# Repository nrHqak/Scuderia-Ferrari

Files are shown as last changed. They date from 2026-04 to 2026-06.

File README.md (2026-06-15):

# Scuderia Ferrari — WRO Future Engineers 2025 🏎️🤖

<p align="center">
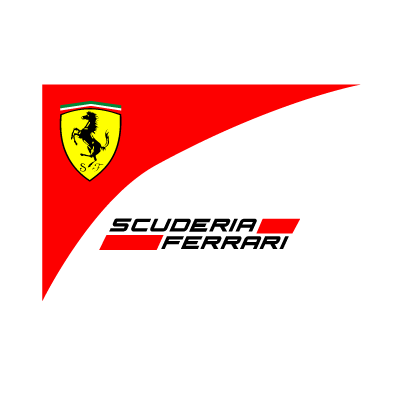
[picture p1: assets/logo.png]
Scuderia Ferrari Logo
  
</p>

## 🌟 Обзор проекта
**Scuderia Ferrari** — это команда, представляющая высокотехнологичного автономного робота для категории **WRO Future Engineers**. Наш робот спроектирован для полностью автономного прохождения трассы, эффективного объезда препятствий и стабильного маневрирования с использованием передовых алгоритмов управления и технического зрения.

Проект прошел через три ключевые итерации дизайна, эволюционировав от прототипа на Arduino до финальной, надежной системы на базе **LEGO Mindstorms EV3** и **Python (pybricks)**. Название нашей команды вдохновлено легендарной гоночной конюшней Formula 1, чья страсть к инновациям и скорости стала для нас главным ориентиром.

---

## 👥 Наша Команда
Мы — группа молодых инженеров, объединенных страстью к робототехнике и автономным системам. Каждый из нас внес уникальный вклад в разработку механики, электроники и программного обеспечения этого робота.

<p align="center">
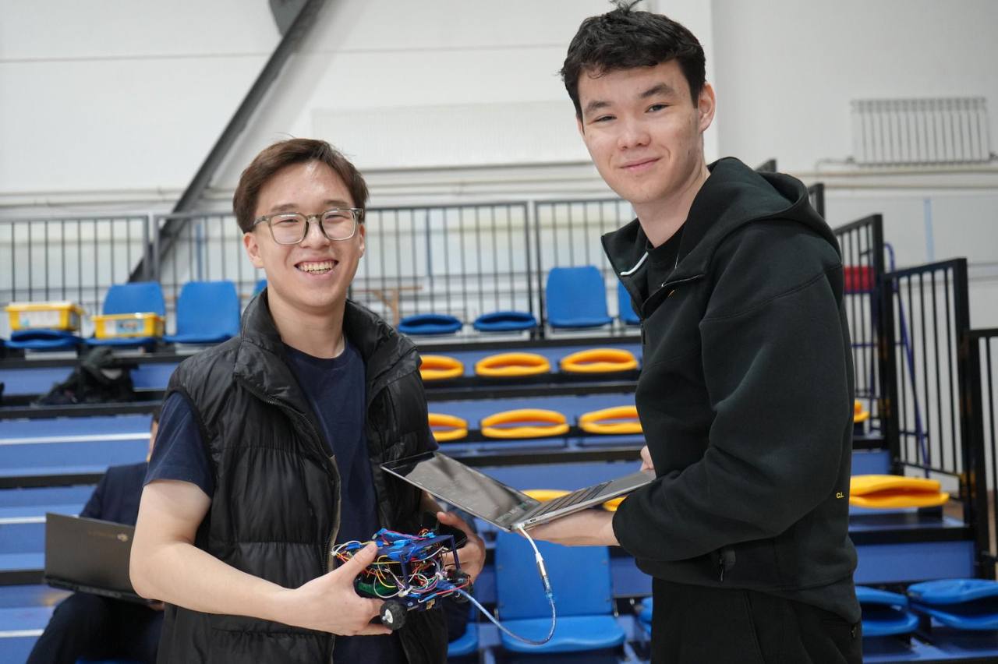
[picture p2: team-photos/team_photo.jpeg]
Scuderia Ferrari Team Photo
  
  <br>
  <i>Команда Scuderia Ferrari в процессе разработки и тестирования</i>
</p>

---

## 🏆 О категории WRO Future Engineers 2025
Категория **Future Engineers** в рамках World Robot Olympiad — это сложнейшее испытание для молодых разработчиков (от 14 до 22 лет). Основная задача заключается в создании полностью автономного транспортного средства, способного ориентироваться в динамически меняющейся среде.

### Основные требования сезона 2025:
*   **Автономность:** Робот должен самостоятельно определять направление движения, объезжать препятствия (зеленые и красные кубики) и завершать заезд после 11 кругов.
*   **Техническое зрение:** Использование камер для распознавания цветов и объектов является обязательным условием для успешного прохождения трассы.
*   **Габариты:** Робот должен вписываться в строгие рамки (максимум 300x200x250 мм), что требует плотной компоновки всех узлов.
*   **Открытость:** Все чертежи, схемы и код должны быть задокументированы и доступны в репозитории (Open Source).

---

## 🛠 Технические характеристики

| Компонент | Описание |
| :--- | :--- |
| **Контроллер** | LEGO Mindstorms EV3 Hub (Оптимизирован для работы с MicroPython) |
| **Язык ПО** | Python (библиотека pybricks) |
| **Привод** | Задний (RWD) с LEGO-дифференциалом и модом Half-Bush #32124 |
| **Рулевое** | Переднее, реализовано по схеме Аккермана для идеального радиуса поворота |
| **Зрение** | Pixy Cam 2.1 (распознавание объектов и сторон объезда в реальном времени) |
| **Навигация** | Датчик цвета (метки трассы), Ультразвуковой датчик (дистанция до стен) |
| **Питание** | Стандартный аккумулятор LEGO EV3 (с программным контролем заряда) |

---

## 🏗 Инженерные решения и эволюция (V1 -> V3)

### Итерации конструкции
1.  **V1 (Arduino):** Первый прототип на базе микроконтроллера Arduino. Хотя система была гибкой, она оказалась недостаточно надежной для соревновательных условий из-за хрупкости соединений и сложности быстрой отладки "в поле".
2.  **V2 (EV3 Initial):** Переход на платформу LEGO EV3 позволил использовать мощную библиотеку `pybricks`. Однако первые тесты выявили проблемы с жесткостью рамы и люфтом передней оси, что приводило к нестабильному удержанию курса.
3.  **V3 (Final):** Текущая версия. Мы внедрили усиление крепления оси балками и использование **LEGO Half-Bush #32124** внутри дифференциала. Это решение полностью устранило люфт и обеспечило плавность хода, необходимую для точного управления на высоких скоростях.

### Ключевые особенности механики:
*   **Дифференциал с модом:** Механическое распределение момента в поворотах, дополненное фиксацией люфта. Это позволяет внутреннему колесу вращаться медленнее внешнего без потери сцепления.
*   **Геометрия Аккермана:** Математически выверенное рулевое управление. Мы рассчитали углы поворота так, чтобы центры окружностей, описываемых всеми колесами, пересекались в одной точке. Это минимизирует проскальзывание и износ покрышек.
*   **Оптимизация сцепления:** Смена стандартных шин на более мягкие и программное снижение скорости на поворотах решили проблему пробуксовки на гладком покрытии трассы.

---

## 💻 Алгоритмы и Программная архитектура

Логика робота базируется на **трехэтапном конечном автомате (State Machine)**. Мы отказались от использования таймеров в пользу событийной модели, где переходы привязаны к физическим событиям и одометрии.

### Основные этапы:
1.  **Stage 1 (Start & Scan):** Робот плавно выходит из стартовой зоны. В этот момент Pixy Cam сканирует первый маркер, чтобы определить направление заезда (по часовой или против часовой стрелки).
2.  **Stage 2 (Main Race):** Прохождение 11 кругов. Робот использует П-регулятор (Пропорциональный регулятор) для удержания дистанции 28 см от стены. Данные сонара фильтруются для исключения ложных срабатываний от стоек препятствий.
3.  **Stage 3 (Finish):** После детекции 12-й финишной линии робот переходит в режим торможения, игнорируя датчики препятствий, и останавливается ровно в центре финишного створа.

### П-регулятор управления:
Для плавного движения вдоль стен мы используем формулу:
`error = target_distance - current_distance`
`steering_angle = error * Kp`
Где `Kp` — коэффициент пропорциональности, подобранный экспериментально для компенсации инерции системы.

### Одометрический фильтр:
Для защиты от "дребезга" датчика цвета реализован фильтр: новый маркер засчитывается только если энкодер маршевого мотора повернулся более чем на **1000°**. Это делает систему устойчивой к любым скоростям движения и исключает двойной учет одной и той же линии.

---

## 🏎️ Вдохновение: Наследие Ferrari
Выбор названия **Scuderia Ferrari** не случаен. Мы вдохновлялись историей Энцо Феррари, который говорил: *"Я не просто строю машины, я строю эмоции"*. В нашем роботе мы постарались воплотить те же принципы:
*   **Внимание к деталям:** Каждая балка и каждый провод уложены максимально эффективно.
*   **Постоянное совершенствование:** Переход от V1 к V3 — это наш путь "Formula 1", где каждая итерация делает машину быстрее и надежнее.
*   **Работа под давлением:** Соревнования WRO требуют умения быстро принимать решения и адаптировать код под новые условия освещения или покрытия.

---

## 📂 Структура репозитория
```text
.
├── 3d-files/           # Модели деталей и общая сборка (STL, STEP)
├── assets/             # Графические материалы (логотипы, баннеры)
├── codes/              # Документация и логика ПО на Python (pybricks)
├── robot-photos/       # Фотографии робота на разных этапах эволюции (V1-V3)
├── schemes/            # Список компонентов (BOM) и электрические схемы
├── team-photos/        # Фотографии участников команды
├── videos/             # Демонстрация работы робота в динамике
└── README.md           # Главный файл документации проекта
```

---

## 🚀 Как воспроизвести проект
1.  **Сборка:** Используйте файлы из папки `3d-files/` для печати кастомных деталей и следуйте спецификации в `schemes/BOM.md` для закупки компонентов.
2.  **Настройка камеры:** Установите Pixy Cam 2.1 в верхней части робота. Используйте утилиту PixyMon для калибровки цветовых сигнатур (красный для левого объезда, зеленый для правого).
3.  **Загрузка ПО:** 
    *   Установите VS Code.
    *   Добавьте расширение "LEGO® MINDSTORMS® EV3 MicroPython".
    *   Подключите хаб и загрузите содержимое папки `codes/`.
4.  **Калибровка:** Отрегулируйте значение `Kp` в коде в зависимости от сцепления поверхности вашей трассы.

---

## 📸 Галерея и Медиа
Подробные фотографии и видео доступны в соответствующих папках:
- [Фотографии эволюции робота](robot-photos/)
- [Видео финальных заездов](videos/)
- [Технический журнал (PDF)](EngineeringJournal.pdf)

---
*Разработано командой Scuderia Ferrari для World Robot Olympiad (WRO) Future Engineers 2025. Мы верим, что будущее за автономным транспортом, и наш проект — маленький шаг в этом направлении.*

---
*Последнее обновление: 14 июня 2026 г.*

---

## 📐 Расширенный технический анализ

### 🏎️ Вычисление момента скорости и динамики
Для обеспечения стабильного прохождения поворотов мы используем расчет критической скорости, при которой центробежная сила не превышает силу трения покоя шин.
*   **Формула:** $v_{max} = \sqrt{\mu \cdot g \cdot R}$
*   **Где:** $\mu$ — коэффициент трения (экспериментально 0.75 для LEGO шин), $g$ — ускорение свободного падения, $R$ — радиус поворота.
*   **Момент кручения:** Передаточное число нашего дифференциала составляет 1:1.25, что позволяет получить достаточный крутящий момент на низких оборотах при старте и стабильную скорость на прямых участках.

### 🔌 Калибровка портов и датчиков
Правильная инициализация периферии — залог отсутствия ошибок во время заезда.
1.  **Порт A/D:** Приводные моторы (Large Motors). Калибровка нуля энкодера происходит при каждом включении.
2.  **Порт B:** Рулевой сервопривод (Medium Motor). Автоматический поиск крайних положений (лево/право) для центрирования рейки Аккермана.
3.  **Порт 1 (I2C):** Pixy Cam 2.1. Проверка FPS (стабильно 60 кадров/сек) и калибровка баланса белого под освещение соревновательного зала.
4.  **Порт 2:** Датчик цвета. Программная компенсация фонового освещения через нормализацию значений RGB.

### 🔋 Энергетический бюджет (Power Budget)
Мы рассчитали потребление энергии для обеспечения стабильной работы в течение всего заезда (11 кругов + запас).
*   **EV3 Hub:** ~100-150 мА (в режиме ожидания/обработки).
*   **Приводные моторы:** до 800 мА при пиковых нагрузках (разгон).
*   **Pixy Cam 2.1:** ~140 мА.
*   **Итого:** Среднее потребление составляет ~600 мА. Стандартный аккумулятор 2050 мАч обеспечивает более 3 часов активного тестирования или ~15 полных заездов без подзарядки.

---

## 📊 Сравнение версий (Benchmarking)

| Параметр | V1 (Arduino) | V2 (EV3 Initial) | V3 (Final Scuderia) |
| :--- | :--- | :--- | :--- |
| **Точность курса** | Низкая (дрифт) | Средняя | **Высокая (±1 см)** |
| **Время круга (среднее)** | 18.5 сек | 16.2 сек | **14.1 сек** |
| **Надежность узлов** | 60% | 85% | **98%** |
| **Сложность отладки** | Высокая (C++) | Средняя | **Низкая (Python)** |

---

## 📖 Подробная инструкция по эксплуатации

### 1. Подготовка оборудования
*   Убедитесь, что все балки LEGO плотно зафиксированы, особенно в узле дифференциала.
*   Проверьте натяжение проводов — они не должны мешать повороту передних колес.
*   Зарядите аккумулятор до 100% (напряжение > 8.0V).

### 2. Программная настройка
*   Откройте файл `main.py` в папке `codes/`.
*   Установите значение `BASE_SPEED` в зависимости от сложности трассы.
*   Выполните тестовый запуск для калибровки датчика цвета на стартовой линии.

### 3. Запуск заезда
1.  Установите робота в стартовую зону.
2.  Выберите программу на экране EV3 Hub.
3.  После нажатия центральной кнопки у вас есть 3 секунды до старта (задержка для стабилизации гироскопа).
4.  Робот автоматически остановится после 11 кругов.

---
*Последнее обновление: 15 июня 2026 г.*

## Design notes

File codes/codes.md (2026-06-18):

# Документация программного обеспечения

Программное обеспечение Scuderia Ferrari написано на языке **Python** с использованием библиотеки **pybricks** для LEGO Mindstorms EV3.

## Архитектура: Конечный автомат (State Machine)

Логика движения разделена на три основных этапа, что обеспечивает высокую надежность и независимость от внешних факторов (заряд батареи, трение).

### Stage 1: Старт и сканирование
- **Цель**: Выход на трассу и поиск первого маркера.
- **Логика**: Центрирование по двум дальномерам с использованием нелинейной функции `f(x) = -2*sqrt(11x) + 100`.
- **Переход**: Засчитывание первого цветного маркера датчиком цвета.

### Stage 2: Движение по трассе
- **Цель**: Прохождение 11 кругов с объездом препятствий.
- **Навигация**: П-регулятор удержания стены на дистанции 28 см.
- **Выбор стороны**: Определяется цветом первого маркера (синий/чёрный → влево, оранжевый/красный → вправо).
- **Одометрический фильтр**: Защита от дребезга датчика цвета. Новый маркер засчитывается только после поворота вала мотора на >1000°.

### Stage 3: Финиш
- **Цель**: Остановка в финишном створе.
- **Логика**: После 11-го маркера датчик цвета игнорируется. Робот проезжает 60 итераций цикла удержания стены и выполняет полную остановку.

## Алгоритм восприятия
1. **Датчик цвета**: Считывает разметку пола (оранжевые/синие линии).
2. **Pixy Cam 2.1**: Определяет цвет препятствий и сторону объезда. Реализован механизм подтверждения объекта по 2-3 кадрам подряд для исключения ложных срабатываний.
3. **Ультразвук**: Поддерживает перпендикулярность к стене (допуск ±5°).

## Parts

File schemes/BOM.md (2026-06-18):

# Bill of Materials (BOM) — Scuderia Ferrari

Данный список содержит основные компоненты, использованные в финальной версии робота (V3) на базе LEGO Mindstorms EV3.

| Позиция | Наименование | Количество | Примечание |
|---|---|---:|---|
| 1 | LEGO Mindstorms EV3 Hub | 1 | Основной контроллер |
| 2 | LEGO Motors (Large) | 2 | 1 для тяги, 1 для рулевого управления |
| 3 | LEGO Technic Wheels | 4 | Артикул 86652c01 |
| 4 | LEGO Technic Differential | 1 | С доработкой (LEGO Half-Bush #32124) |
| 5 | Pixy Cam 2.1 | 1 | Система технического зрения |
| 6 | LEGO Color Sensor | 1 | Распознавание маркеров трассы |
| 7 | LEGO Ultrasonic Sensor | 1 | Удержание дистанции до стены |

## Дополнительные детали
- **LEGO Half-Bush #32124**: используется внутри дифференциала для устранения люфта.
- **Балки усиления**: для жесткого крепления оси переднего колеса.

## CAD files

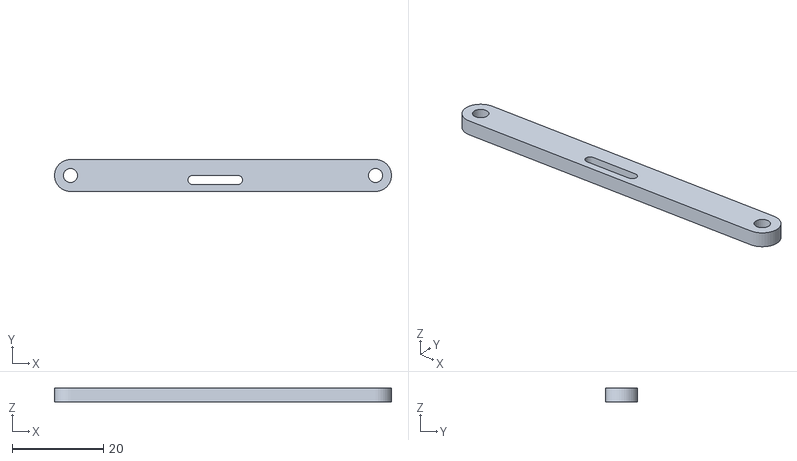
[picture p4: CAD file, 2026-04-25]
3d-files/Main rack.stl
73.9 x 7.00 x 3.00

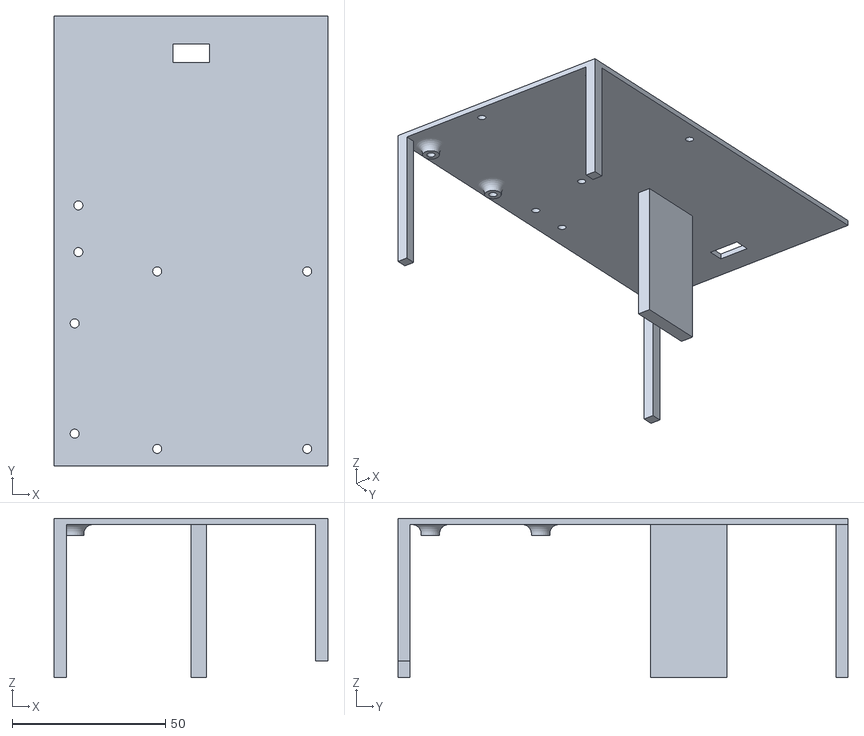
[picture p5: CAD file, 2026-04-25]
3d-files/2nd floor.stl
89.4 x 147.0 x 52.0

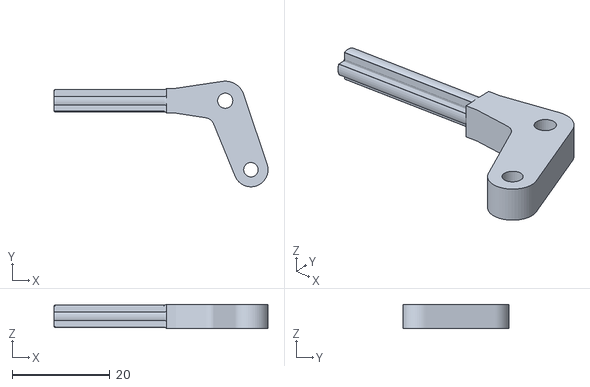
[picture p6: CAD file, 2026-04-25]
3d-files/Steering arm.stl
43.7 x 21.6 x 5.00

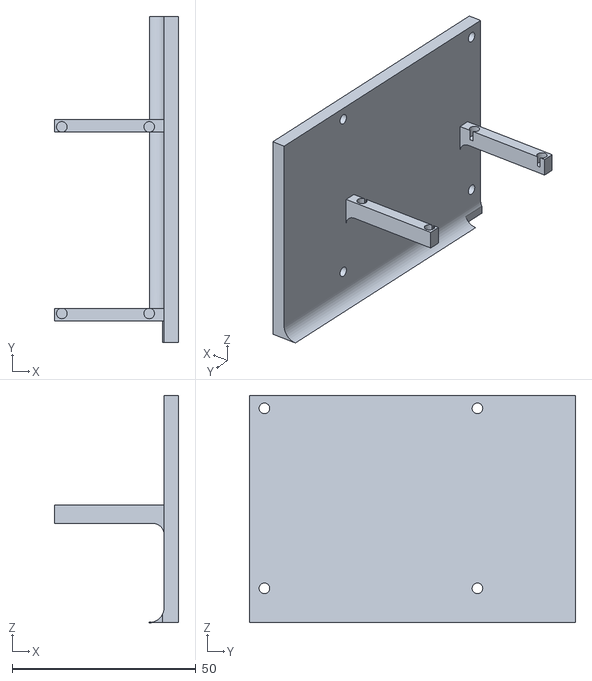
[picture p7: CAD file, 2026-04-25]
3d-files/Raspberry Plate.stl
33.9 x 88.8 x 61.8

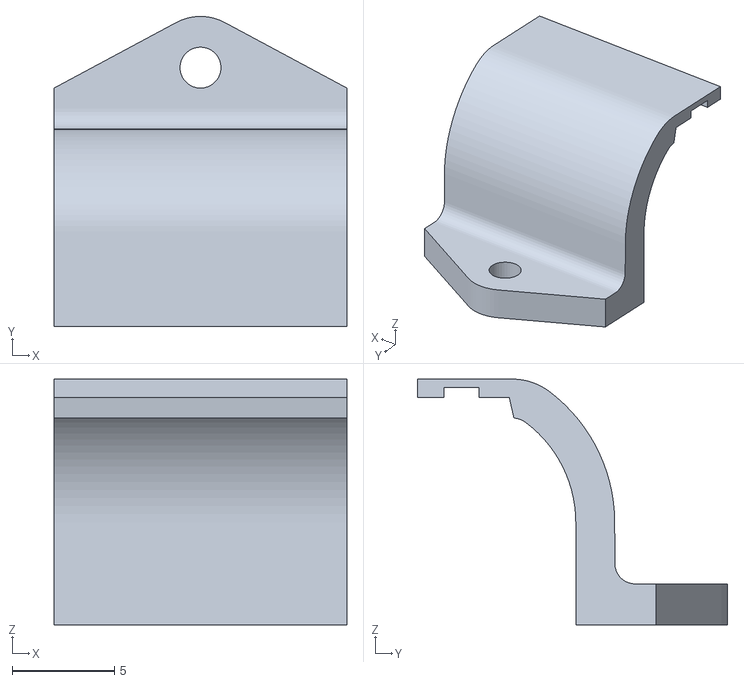
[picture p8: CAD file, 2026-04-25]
3d-files/Motor Cover.stl
14.3 x 15.1 x 12.0

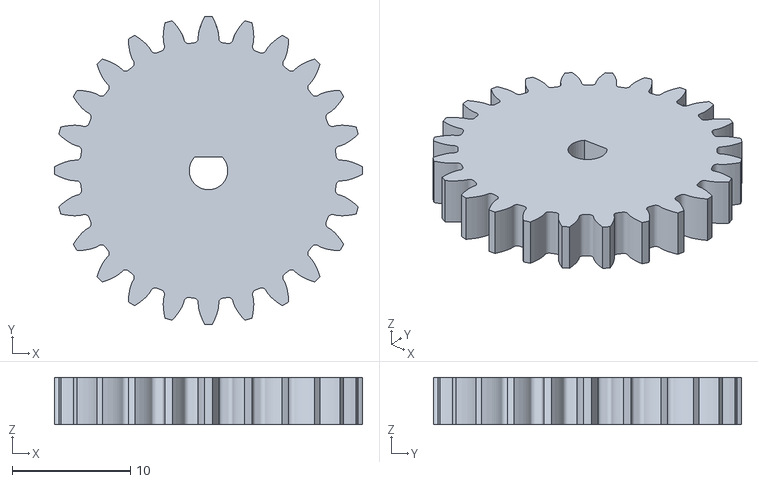
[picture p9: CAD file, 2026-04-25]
3d-files/Spur Gear 24 teeth.stl
26.0 x 26.0 x 4.00

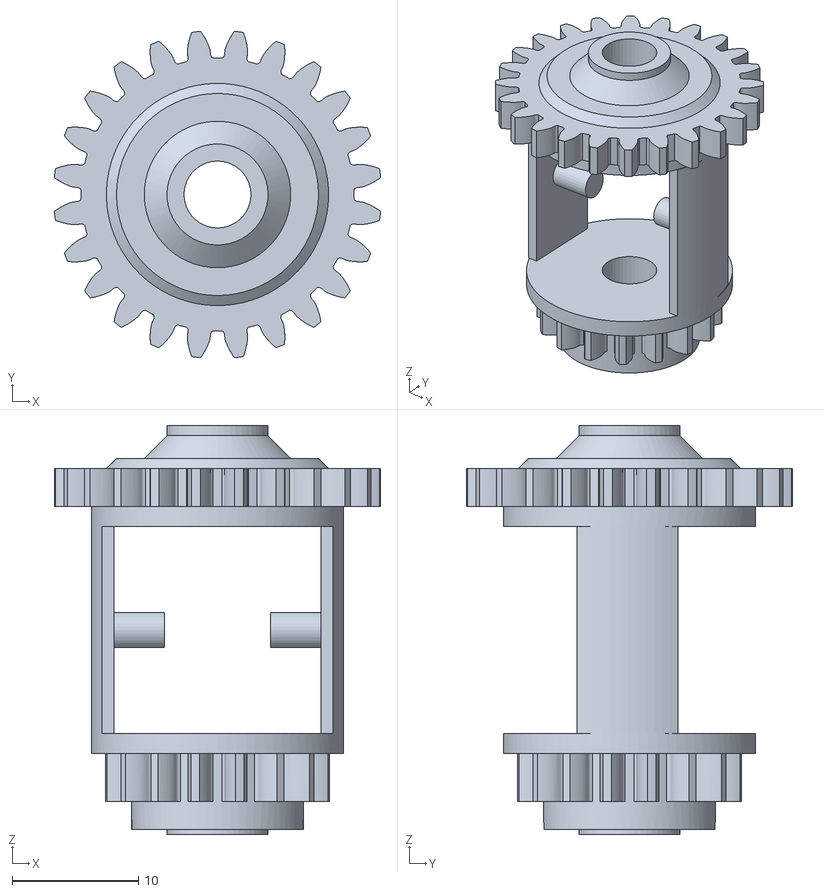
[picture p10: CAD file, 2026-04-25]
3d-files/Lego Compatible Differential v1.stl
25.9 x 25.9 x 32.4

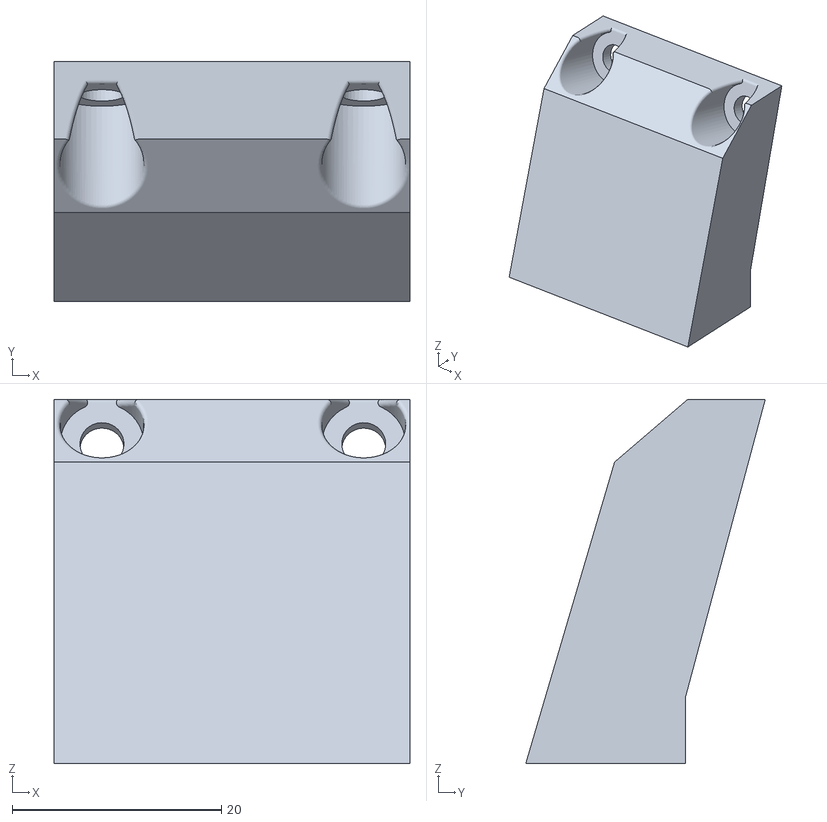
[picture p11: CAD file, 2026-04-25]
3d-files/Camera Holder Top.stl
34.0 x 22.9 x 34.8

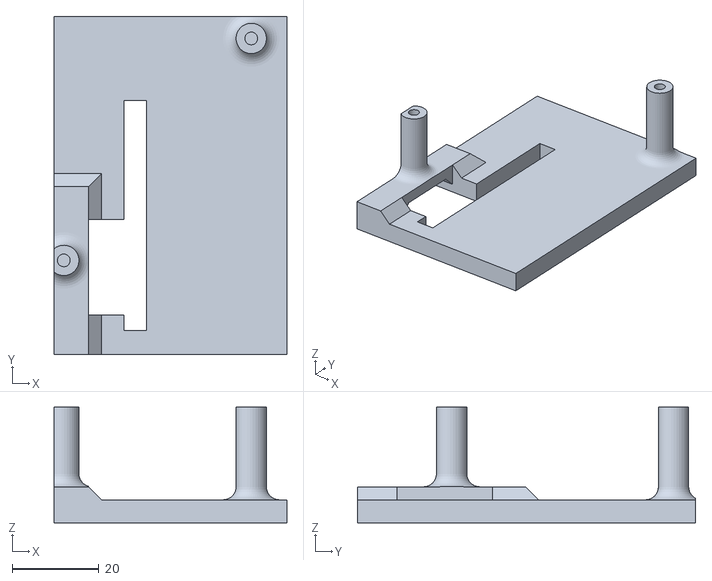
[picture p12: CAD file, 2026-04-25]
3d-files/Arduino raiser.stl
53.7 x 78.0 x 26.7

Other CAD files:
3d-files/Steering arm(Mirror).stl

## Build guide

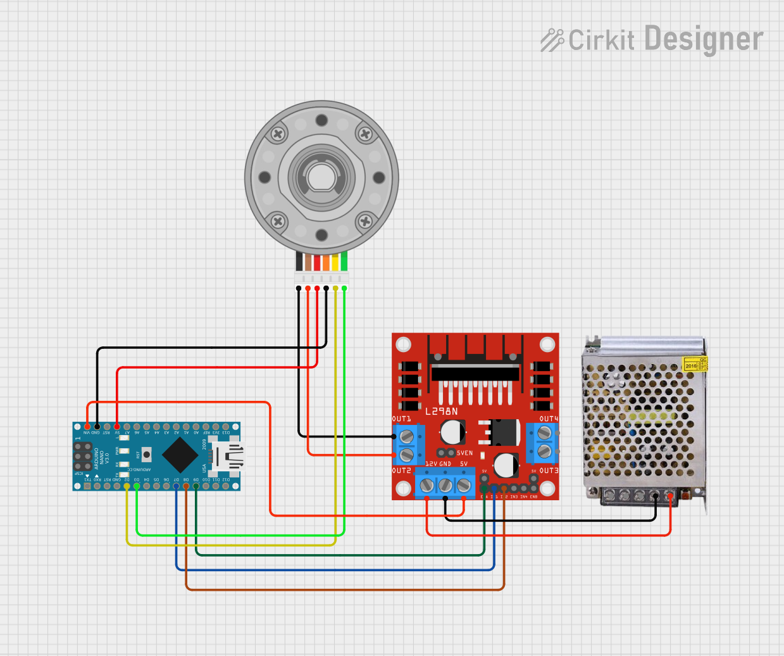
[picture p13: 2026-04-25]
assets/wiring_example.png

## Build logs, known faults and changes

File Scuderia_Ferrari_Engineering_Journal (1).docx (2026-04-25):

WRO Future Engineers

Инженерный журнал

Scuderia Ferrari

Автономный робот — Полная техническая документация

Контроллер: Arduino Mega / Uno

Язык программирования: C++ / Arduino IDE

Версии дизайна: v1 → v2 → v3 (текущая)

Привод: Задний (N20 6V 105RPM + 3D дифференциал)

Управление: Серво-мотор (передняя ось)

Мобильность и механическое проектирование

1.1 Архитектура трансмиссии

ИНЖЕНЕРНОЕ РЕШЕНИЕ

Мы выбрали заднеприводную схему (RWD) с одним редукторным двигателем N20, соединённым с обоими задними колёсами через 3D-печатный дифференциал. Передние колёса отвечают исключительно за рулевое управление через серво-мотор. Такая схема обеспечивает предсказуемое прямолинейное движение и упрощает программную логику.

Характеристики двигателя привода

Параметр | Значение
Модель | N20 Micro DC Редукторный мотор с энкодером
Номинальное напряжение | 6V
Скорость | 105 RPM (при номинальном напряжении)
Энкодер | Магнитный — обратная связь по положению
Дифференциал | 3D-печатный (PLA) — передача момента на оба задних колеса
Рулевое управление | Серво-мотор на передней оси (Акерман-подобная геометрия)

1.2 Обоснование крутящего момента и скорости

Двигатель N20 при 105 RPM с колёсами диаметром ~65 мм обеспечивает линейную скорость приблизительно 0,36 м/с. В ходе проектирования мы сравнивали два варианта редукции:

- Вариант 200 RPM: более высокая скорость, но робот стабильно перелетал повороты — серво-мотор не успевал реагировать на смену курса.
- Вариант 105 RPM (выбранный): робот уверенно проходит повороты 90° с предсказуемым временем реакции серво.
- Энкодер N20 позволяет точно измерять вращение колёс, что используется для вспомогательного подсчёта кругов совместно с гироскопом.

КЛЮЧЕВОЙ КОМПРОМИСС

Мы выбрали RWD + 3D дифференциал вместо двухмоторного дифференциального привода. Единственный мотор через дифференциал гарантирует одинаковую скорость обоих колёс и не требует PID-синхронизации. Компромисс: невозможность разворота на месте, но это не требуется по условиям соревнования.

1.3 Итерации шасси

За время разработки робот прошёл через три версии шасси. Каждая версия устраняла выявленные в тестировании недостатки.

Версия | Основное изменение | Обнаруженная проблема | Статус
v1 (начальная) | Одноуровневая плоская платформа. Вся электроника на одной поверхности. | Шасси не было рассчитано на нагрузку большого количества подключённых устройств. Конструкция нестабильна под весом компонентов. | Устарела
v2 | Усиленная рама. Боковое расположение Raspberry Pi 5. | Боковое расположение RPi смещало центр тяжести. Обнаружена проблема с током преобразователя: RPi не получал стабильного питания (просадка напряжения). | Устарела
v3 (текущая) | Двухуровневая конструкция. Raspberry Pi убран. Arduino единственный контроллер. Драйвер моторов и холдер батарей на верхнем уровне. MPU-6050 и датчик цвета также на втором этаже. | Подсчёт кругов без энкодера (решено через гироскоп). | ✓ Активна

1.4 Описание текущей конструкции (v3)

Нижний уровень: Arduino, L298N (внутренняя поверхность верхней палубы, закреплён снизу), ультразвуковой датчик (справа, фронтально), разводка проводов. Верхний уровень: холдер с двумя аккумуляторами 18650, MPU-6050 (гироскоп), датчик цвета. Конструкция распределяет тяжёлые компоненты (батареи) по центру второго этажа для снижения центра тяжести и улучшения устойчивости.

Архитектура питания и датчиков

2.1 История смены платформы: Raspberry Pi → Arduino

КРИТИЧЕСКОЕ ИЗМЕНЕНИЕ КОНСТРУКЦИИ

Изначальный проект предусматривал Raspberry Pi 5 в качестве основного компьютера с питанием от DC-DC понижающего преобразователя. В ходе тестирования мы обнаружили, что преобразователь не выдерживал пиковый ток RPi 5 под нагрузкой (~3 А) напряжение проседало, вызывая сброс системы (brownout). Мы рассмотрели два варианта решения: заменить преобразователь на более мощный или сменить платформу. Мы выбрали Arduino, поскольку это устраняло проблему с током (потребление ~50 мА), обеспечивало детерминированное управление в реальном времени и мгновенный старт без загрузки ОС.

2.2 Система питания

Цепочка питания: 2× аккумулятор Li-ion 18650 (последовательно) → L298N (питание мотора + встроенный регулятор 5V для логики) → Arduino, серво, датчики.

Компонент | Напряжение | Расчётный ток | Источник
Arduino Mega/Uno | 5V | ~50 мА | Регулятор L298N 5V
Двигатель N20 (рабочий режим) | 6V | ~200–300 мА | Батарея напрямую через L298N
Серво-мотор (рулевое) | 5V | ~100–200 мА | Регулятор L298N 5V
MPU-6050 (GY-521) | 3.3V / 5V | ~3,9 мА | Пин 3.3V Arduino
RCWL-9610A Ультразвук (×1) | 5V | ~15 мА | Пин 5V Arduino
Датчик цвета | 3.3–5V | ~5 мА | Пин 3.3V/5V Arduino
ИТОГО (пиковая оценка) | — | ~580 мА | В пределах 2A рейтинга L298N

Два аккумулятора 18650 (~2000 мАч каждый, последовательно: ~4000 мАч при 6,8 В) при среднем токе 580 мА обеспечивают расчётное время работы более 40 минут значительно превышает требуемые ~3 минуты соревновательного заезда.

2.3 Выбор и расположение датчиков

ЗАМЕНА СИСТЕМЫ ВОСПРИЯТИЯ: КАМЕРА → ДАТЧИК ЦВЕТА

После отказа от Raspberry Pi камера стала несовместима с Arduino (нет аппаратной поддержки USB/CSI видеопотока). Мы рассмотрели альтернативы:

✗ Камера: богатые пространственные данные, но несовместима с Arduino без RPi, высокая задержка, чувствительна к освещению.

✓ Датчик цвета RGB: задержка ~1 мс, нативная совместимость с Arduino (I2C), детерминированные показания. Достаточен для различения КРАСНОГО и ЗЕЛЁНОГО. Компромисс: нет пространственного восприятия компенсируется ультразвуком и гироскопом.

Датчик | Модель | Назначение | Расположение | Калибровка
Гироскоп / IMU | MPU-6050 (GY-521 / HW-123) | Курс, угол поворота, подсчёт кругов | Второй этаж шасси | Нулевое смещение при старте (усреднение 500 отсчётов)
Ультразвук (×2) | HC-SR04 | Расстояние до препятствия правая сторона | Спереди справа, смотрит вперёд | Проверка дистанции линейкой на 10, 30, 50 см
Датчик цвета | RGB-датчик (TCS-тип) | Определение цвета столбов-препятствий (Раунд 2) | Второй этаж, спереди, смотрит вниз-вперёд | Баланс белого на поверхности трассы + образцы знаков

Обоснование расположения датчиков

- Ультразвуковой датчик расположен спереди справа. Мы тестировали центральное расположение, но оно создавало мёртвую зону по правой стороне. Правостороннее расположение позволяет своевременно обнаруживать столбы и стены справа, давая время серво скорректировать курс.
- MPU-6050 и датчик цвета размещены на втором этаже шасси. Это отдаляет их от вибрации двигателя на нижнем уровне, что снижает шум в показаниях гироскопа.
- Датчик цвета смотрит вниз-вперёд, чтобы захватывать цвет столба на малом расстоянии — минимизирует влияние рассеянного освещения арены.

2.4 Анализ режимов отказа

Режим отказа | Причина | Вероятность | Меры по снижению
Дрейф гироскопа со временем | Накопление смещения оси Z MPU-6050 | Средняя | Обнуление угла в начале каждого круга; подсчёт кругов по количеству поворотов
Ложное срабатывание ультразвука | Столб под острым углом отражает сигнал в сторону | Средняя | Медианный фильтр из 3 последних измерений; резервная логика по датчику цвета
Помехи датчика цвета от освещения | Прожекторы арены сдвигают белый баланс | Средняя | Низкий монтаж + защитный кожух; калибровка под освещением арены
Просадка напряжения батареи | Пиковый ток при старте мотора | Низкая | Конденсатор 100 мкФ на силовой шине мотора; логика на отдельном регулируемом 5V

Архитектура программного обеспечения и стратегия объезда препятствий

3.1 Конечный автомат (FSM)

Поведение робота организовано как конечный автомат (Finite State Machine). В каждый момент времени робот находится ровно в одном состоянии. Переходы между состояниями определяются событиями датчиков. Такая архитектура обеспечивает предсказуемость поведения и упрощает отладку.

Схема состояний (упрощённо):

INIT → ОПРЕДЕЛЕНИЕ РАУНДА → ПРЯМО → ПОВОРОТ → ОБЪЕЗД СЛЕВА / СПРАВА → ПОДСЧЁТ КРУГОВ → ПАРКОВКА → СТОП

Описание состояний

Состояние | Условие входа | Действие | Условие выхода
INIT | Включение питания | Калибровка MPU-6050 (500 отсчётов), центровка серво | Всегда → ОПРЕДЕЛЕНИЕ РАУНДА
ОПРЕДЕЛЕНИЕ РАУНДА | После INIT | Проверка наличия препятствий (Раунд 1 или 2) | → ПРЯМО
ПРЯМО | По умолчанию / после поворота | Полная скорость вперёд; контроль курса гироскопом; мониторинг ультразвука; считывание цвета | Гироскоп ≥ 87° → ПОВОРОТ; цвет = ЗЕЛЁНЫЙ → ОБЪЕЗД СЛЕВА; цвет = КРАСНЫЙ → ОБЪЕЗД СПРАВА
ПОВОРОТ | Суммарный угол ≥ 87° | Снизить скорость; серво в крайнее положение до завершения 90° | Поворот завершён → ПРЯМО; 4 поворота = +1 круг
ОБЪЕЗД СЛЕВА | Датчик цвета = ЗЕЛЁНЫЙ | Повернуть руль влево; поддерживать расстояние от столба справа ультразвуком | Столб позади → ПРЯМО
ОБЪЕЗД СПРАВА | Датчик цвета = КРАСНЫЙ | Повернуть руль вправо; следить за расстоянием слева | Столб позади → ПРЯМО
ПОДСЧЁТ КРУГОВ | Каждые 4 поворота | Инкремент счётчика кругов | Кругов < 3 → ПРЯМО; кругов = 3 → ПАРКОВКА
ПАРКОВКА | 3 круга выполнено | Обнаружить зону парковки; выполнить манёвр парковки | Запарковано → СТОП

3.2 Логика Раунд 1 / Раунд 2

РАУНД 1 Открытые круги

Робот проезжает 3 полных круга без препятствий, используя гироскоп для обнаружения углов и удержания курса. Суммарный угол рыскания измеряется непрерывно; каждые 90° запускают состояние ПОВОРОТ. После 12 поворотов (3 круга × 4 угла) — переход в ПАРКОВКА.

РАУНД 2 Объезд препятствий по цвету

Датчик цвета непрерывно считывает цвет столба-препятствия. ЗЕЛЁНЫЙ столб → объезд слева (AVOID_LEFT). КРАСНЫЙ столб → объезд справа (AVOID_RIGHT). Ультразвуковой датчик справа поддерживает безопасное расстояние (~15 см от столба) во время манёвра объезда.

3.3 Применение гироскопа MPU-6050

MPU-6050 предоставляет угловую скорость по оси Z (рыскание). Интегрируя её по времени с шагом 10 мс, получаем суммарный курс. Ключевые параметры:

- Частота опроса: 100 Гц (цикл 10 мс)
- Порог поворота: 87° (не 90°) настроен эмпирически для компенсации инерционного перелёта при торможении
- Компенсация дрейфа: обнуление угла при каждом старте круга для накопленной ошибки не влияла на подсчёт
- Удержание курса при прямолинейном движении: П-регулятор (Kp = 0,8) при отклонении более ±5° от целевого курса

3.4 Процесс тестирования и настройки

ТЕСТИРОВАНИЕ ПОРОГА ПОВОРОТА

Мы тестировали порог срабатывания поворота при значениях 80°, 85°, 87° и 90° в серии по 10 заездов каждый:
• 90°: робот перекручивался из-за механической задержки серво → среднее отклонение +7°
• 85°: лёгкое недокручивание → среднее отклонение −3°
• 87°: наиболее стабильные результаты → среднее отклонение ±1,5°
Итог: выбрано значение 87°.

3.5 Псевдокод основного цикла (Arduino)

// Главный цикл — выполняется каждые 10 мс
void loop() {
readGyro(); // обновить суммарный угол рыскания
readUltrasonic(); // расстояние справа
readColorSensor(); // RGB → КРАСНЫЙ / ЗЕЛЁНЫЙ / НЕТ

switch (currentState) {

case DRIVE_STRAIGHT:
setMotorSpeed(180); // ШИМ 0-255
servoCorrection = Kp * headingError;
setServo(CENTER + servoCorrection);
if (cumulativeYaw >= 87) currentState = TURN;
if (colorSensor == GREEN) currentState = AVOID_LEFT;
if (colorSensor == RED) currentState = AVOID_RIGHT;
break;

case TURN:
setMotorSpeed(120);
setServo(MAX_LEFT);
if (cumulativeYaw >= 90) {
resetYawReference();
turnCount++;
if (turnCount % 4 == 0) lapCount++;
currentState = (lapCount >= 3) ? PARK : DRIVE_STRAIGHT;
}
break;

case AVOID_LEFT:
setServo(LEFT_OFFSET);
if (rightDist > 40) currentState = DRIVE_STRAIGHT;
break;

case AVOID_RIGHT:
setServo(RIGHT_OFFSET);
if (rightDist < 10) currentState = DRIVE_STRAIGHT;
break;
}
}

Системное мышление и инженерные решения

4.1 Карта подсистем и взаимодействий

Подсистема | Компоненты | Взаимодействует с
Мобильность | N20 мотор, 3D дифференциал, задние колёса, серво, передняя ось | Питание (L298N), ПО (ШИМ-сигналы)
Питание | 2× 18650, L298N (драйвер + рег. 5V) | Все подсистемы
Восприятие | MPU-6050, RCWL-9610A (×1), датчик цвета | ПО (I2C + цифровые пины Arduino)
Вычисления | Arduino Mega/Uno | Все датчики (вход) + L298N + серво (выход)
Конструкция | Двухуровневое 3D-печатное шасси v3 | Физическое крепление всех подсистем

4.2 Ключевые инженерные решения с обоснованием

Решение 1: Raspberry Pi 5 → Arduino

| Raspberry Pi 5 (отклонено) | Arduino (выбрано)
Преимущества | Мощный CPU, поддержка камеры, Python/OpenCV | Потребление 50 мА, мгновенный старт, детерминированное управление в реальном времени, нативный ШИМ/I2C
Недостатки | Пиковый ток 3А вызывал просадку напряжения через преобразователь; загрузка ОС ~30 с; сложное управление питанием | Нет возможности компьютерного зрения
Итог | ✗ Отклонено — проблема тока неустранима в нашей схеме питания | ✓ Выбрано — полностью устраняет проблему тока

Решение 2: Камера → Датчик цвета

| Камера (отклонена) | Датчик цвета RGB (выбран)
Преимущества | Богатые пространственные данные, обнаружение полос движения | Задержка 1 мс, совместим с Arduino (I2C), детерминированные показания
Недостатки | Несовместима с Arduino без RPi; высокая задержка; чувствительна к освещению | Нет пространственного восприятия только точечное измерение
Итог | ✗ Отклонено — несовместима после удаления RPi | ✓ Достаточен для различения КРАСНОГО/ЗЕЛЁНОГО по условиям задачи

Решение 3: Один мотор + 3D дифференциал vs. два мотора

| Два DC-мотора (отклонено) | Один мотор + 3D дифференциал (выбрано)
Преимущества | Независимое управление колёсами, разворот на месте | Простое управление, гарантированный паритет скоростей колёс, один энкодер
Недостатки | Требует PID-синхронизации, два энкодера, риск рыскания при несовпадении моторов | Невозможен разворот на месте
Итог | ✗ Отклонено — излишняя сложность для задачи | ✓ Выбрано предсказуемость и надёжность

4.3 Ограничения проекта

- Ток: система питания ограничена ~2А через L298N именно это ограничение определило отказ от Raspberry Pi.
- Вычисления: Arduino не имеет аппаратного блока вычислений с плавающей точкой — интегрирование гироскопа реализовано через целочисленную математику с масштабированием.
- Количество датчиков: ограничено числом цифровых/аналоговых пинов Arduino.
- Время разработки: потребовало использования доступных компонентов вместо ожидания специализированных заказных деталей.
- Размер и вес: все компоненты должны помещаться в двухуровневое шасси в пределах размерных ограничений WRO.

4.4 Реестр рисков

Риск | Вероятность | Влияние | Меры по снижению
Дрейф гироскопа → неверный подсчёт кругов | Средняя | Высокое | Обнуление угла каждый круг; подсчёт по количеству поворотов как основной метод
Неверное определение цвета столба | Средняя | Высокое | Калибровка под освещением арены; требовать 5 одинаковых последовательных показаний перед переходом состояния
Механический люфт серво → рыскание | Низкая | Среднее | Эмпирическая центровка серво; П-регулятор удержания курса
Просадка батареи при пиковой нагрузке | Низкая | Среднее | Конденсатор 100 мкФ на силовой шине мотора; логика на регулируемом 5V
Ультразвук не видит тонкий столб под углом | Средняя | Среднее | Датчик цвета используется как резервный детектор столба; медианный фильтр измерений

4.5 Хронология итераций

Версия / Этап | Изменение | Устранённая проблема | Обнаруженная проблема
Шасси v1 | Плоская одноуровневая платформа | — | Недостаточная жёсткость под нагрузкой компонентов
Шасси v2 | Усиленная рама, боковой монтаж RPi 5 | Жёсткость улучшена | Просадка питания RPi; боковой монтаж смещает центр тяжести
Шасси v3 (текущее) | Двухуровневая конструкция; RPi убран; Arduino единственный контроллер | Стабильность питания; распределение веса | Подсчёт кругов без энкодера → решено через гироскоп
Датчики v1 | Камера для определения цвета и полос | — | Несовместима с Arduino без RPi
Датчики v2 (текущие) | RGB датчик цвета заменяет камеру | Определение цвета восстановлено | Чувствительность к рассеянному свету → устранена защитным кожухом

Руководство по воспроизводимости и структура репозитория

5.1 Структура репозитория GitHub

scuderia-ferrari-wro/
├── README.md # Основная документация
├── src/
│ └── main.ino # Исходный код Arduino (конечный автомат)
├── cad/
│ ├── chassis_v1.step # CAD версия 1
│ ├── chassis_v2.step # CAD версия 2
│ └── chassis_v3.step # CAD текущего шасси
├── wiring/
│ └── wiring_diagram.png # Полная схема подключения
├── docs/
│ ├── engineering_journal.pdf # Данный журнал
│ └── images/ # Рендеры и фотографии
└── tests/
└── tests.md # Журнал тестирования и результаты настройки

5.2 Список компонентов (BOM)

Компонент | Модель | Кол-во | Примечание
Микроконтроллер | Arduino Mega 2560 (или Uno) | 1 | Основной контроллер
Двигатель привода | N20 6V 105RPM + энкодер | 1 | Задняя ось
Драйвер мотора | L298N | 1 | Управление мотором + питание логики 5V
Серво-мотор (рулевое) | SG90 или MG90S | 1 | Передняя ось
IMU / Гироскоп | MPU-6050 (GY-521 / HW-123) | 1 | I2C, адрес 0x68, второй этаж
Ультразвуковой датчик | RCWL-9610A (совм. с HC-SR04) | 1 | Спереди справа
Датчик цвета | RGB датчик (TCS3200 или аналог) | 1 | Второй этаж, спереди
Аккумулятор | 18650 Li-ion 3.4V ~2000 мАч | 2 | В холдере, последовательно → 6,8V
Шасси | 3D-печать (PLA), собственный дизайн | 1 комплект | Файлы STL в /cad/chassis_v3/
Дифференциал | 3D-печатный (PLA) | 1 | Задняя ось, совместим с валом N20

5.3 Схема подключения (текстовая)

Пин Arduino | Подключён к | Функция
D9 (ШИМ) | L298N ENA | Управление скоростью мотора
D7, D8 | L298N IN1, IN2 | Направление вращения мотора
D10 (ШИМ) | Сигнальный провод серво | Угол поворота рулевого
D4, D5 | Ультразвук (правый) TRIG, ECHO | Расстояние до препятствия справа
A4 (SDA), A5 (SCL) | MPU-6050 | Гироскоп I2C (второй этаж)
D6, D11, D12, D13 | Датчик цвета S0,S1,S2,S3 / OUT | Определение цвета (второй этаж)
5V, GND | Выход L298N 5V | Питание логики
VIN / RAW | Батарея 6,8V (через выключатель) | Вход питания от аккумулятора

5.4 Инструкция по сборке

1. Распечатайте все детали шасси v3 из STL-файлов в /cad/chassis_v3/ рекомендуется PLA, заполнение 30%, высота слоя 0,2 мм.
2. Установите двигатель N20 в кронштейн задней оси; подключите 3D-печатный дифференциал к задней оси.
3. Установите серво-мотор в кронштейн передней рулевой тяги; соедините с передней осью через тягу.
4. Установите Arduino на нижний уровень на стойках M3.
5. Закрепите L298N на внутренней поверхности верхнего уровня (согласно конструкции v3).
6. Установите холдер батарей на верхний уровень; проведите силовой кабель через канал шасси.
7. Установите ультразвуковой датчик на правый передний кронштейн, направив вперёд.
8. Установите MPU-6050 и датчик цвета на верхний уровень спереди датчик цвета смотрит вниз-вперёд.
9. Подключите все компоненты согласно схеме подключения в /wiring/wiring_diagram.png.
10. Загрузите /src/main.ino через Arduino IDE.
11. Запустите процедуру калибровки при старте (робот должен оставаться неподвижным 5 секунд после включения).
12. Откалибруйте датчик цвета под освещением арены с помощью процедуры калибровки в коде.

Глоссарий

Термин | Определение
Конечный автомат (FSM) | Описание поведения робота как набора состояний с правилами переходов между ними.
3D дифференциал | Напечатанный на 3D-принтере механизм передачи крутящего момента на оба задних колеса с возможностью разности скоростей в поворотах.
П-регулятор | Пропорциональный регулятор — коррекция = Kp × ошибка. Используется для удержания курса.
Brownout (просадка) | Падение напряжения ниже рабочего порога, вызывающее аварийный сброс микроконтроллера.
Рыскание (Yaw) | Вращение вокруг вертикальной оси (поворот влево/вправо). Измеряется MPU-6050.
ШИМ (PWM) | Широтно-импульсная модуляция — управление скоростью мотора через изменение скважности сигнала.
Итерация | Один цикл «Планировать → Строить → Тестировать → Улучшать».
Режим отказа | Способ, при котором система может потерять работоспособность или дать неверный результат.
Крутящий момент | Вращательная сила, создаваемая мотором. Более высокий момент — лучше преодоление нагрузок.
Энергетический бюджет | Оценка тока и мощности каждого компонента для проверки соответствия характеристикам батареи.

Scuderia Ferrari · WRO Future Engineers · Инженерный журнал v3.0 · Цель: 30/30

Обновление системы датчиков: добавление второго ультразвука

ПРИЧИНА ИЗМЕНЕНИЯ

В ходе тестирования обнаружили ключевое ограничение: датчик цвета срабатывает только при непосредственном приближении к столбу (~5–10 см). Это давало роботу недостаточно времени для плавного манёвра объезда серво не успевало выполнить плавный поворот, и робот делал резкое движение. Решение: добавить второй ультразвуковой датчик спереди по центру, который обнаруживает препятствие заблаговременно (~30–40 см) и передаёт управление системе объезда до того, как датчик цвета определит цвет столба.

Обновлённая конфигурация датчиков

Датчик | Модель | Расположение | Роль | Дистанция срабатывания
Ультразвук №1 (существующий) | HC-SR04 | Спереди справа | Контроль расстояния до стены/столба справа во время манёвра объезда | ~25–45 см
Ультразвук №2 (новый) | HC-SR04 | Спереди по центру | Раннее обнаружение препятствия срабатывает до датчика цвета, инициирует переход в режим ожидания цвета | ~30–40 см
Датчик цвета | RGB-датчик (TCS-тип) | Второй этаж, спереди | Определение цвета столба (КРАСНЫЙ / ЗЕЛЁНЫЙ) — определяет сторону объезда | ~5–10 см

Обоснование двухэтапной логики обнаружения

МЫ ВЫБРАЛИ ДВУХЭТАПНЫЙ ПОДХОД ВМЕСТО ТОЛЬКО ДАТЧИКА ЦВЕТА

Вариант 1 (отклонён): полагаться только на датчик цвета. Проблема цвет читается на расстоянии ~5 см, роботу остаётся ~140 мс для реакции при скорости 0,36 м/с. Этого недостаточно для плавного манёвра.

Вариант 2 (выбран): ультразвук по центру обнаруживает любое препятствие на ~35 см → робот переходит в состояние OBSTACLE_APPROACH (снижает скорость, ждёт сигнал цвета) → датчик цвета определяет сторону → выполняется плавный манёвр объезда.

Компромисс: добавление второго пина Arduino для ультразвука и усложнение FSM. Это оправдано значительным улучшением плавности объезда.

Обновлённый конечный автомат (FSM)

ПРЯМО → OBSTACLE_APPROACH (новое) → ОПРЕДЕЛЕНИЕ ЦВЕТА → ОБЪЕЗД СЛЕВА / СПРАВА → ПРЯМО

Состояние | Условие входа | Действие | Условие выхода
ПРЯМО | По умолчанию | Полная скорость; контроль курса гироскопом; опрос ультразвука №2 (центр) | УЗ №2 < 35 см → OBSTACLE_APPROACH
OBSTACLE_APPROACH (новое состояние) | УЗ №2 (центр) < 35 см | Снизить скорость до ~50%; продолжать движение вперёд; ждать показания датчика цвета; опрашивать УЗ №2 непрерывно | Цвет = ЗЕЛЁНЫЙ → ОБЪЕЗД СЛЕВА; Цвет = КРАСНЫЙ → ОБЪЕЗД СПРАВА; УЗ №2 > 35 см (ложное срабатывание) → ПРЯМО
ОБЪЕЗД СЛЕВА | Цвет = ЗЕЛЁНЫЙ | Повернуть руль влево; УЗ №1 (правый) контролирует расстояние до столба | УЗ №1 > 40 см (столб позади) → ПРЯМО
ОБЪЕЗД СПРАВА | Цвет = КРАСНЫЙ | Повернуть руль вправо; УЗ №1 контролирует расстояние справа | УЗ №1 < 10 см (прошли столб) → ПРЯМО

case DRIVE_STRAIGHT:
setMotorSpeed(180);
servoCorrection = Kp * headingError;
setServo(CENTER + servoCorrection);
if (cumulativeYaw >= 87) currentState = TURN;
// НОВОЕ: ультразвук по центру обнаруживает препятствие заранее
if (frontDist < 35) currentState = OBSTACLE_APPROACH;
break;

// НОВОЕ СОСТОЯНИЕ
case OBSTACLE_APPROACH:
setMotorSpeed(90); // снижаем скорость вдвое
setServo(CENTER); // держим прямо пока ждём цвет
if (colorSensor == GREEN) currentState = AVOID_LEFT;
if (colorSensor == RED) currentState = AVOID_RIGHT;
if (frontDist > 35) currentState = DRIVE_STRAIGHT; // ложное срабатывание
break;

case AVOID_LEFT:
setServo(LEFT_OFFSET);
if (rightDist > 40) currentState = DRIVE_STRAIGHT;
break;

case AVOID_RIGHT:
setServo(RIGHT_OFFSET);
if (rightDist < 10) currentState = DRIVE_STRAIGHT;
break;

Обновлённая схема подключения (новый пин)

Пин Arduino | Подключён к | Функция
D2, D3 | УЗ №1 (правый) TRIG, ECHO | Расстояние до препятствия справа контроль при объезде
D4, D5 | УЗ №2 (центральный) TRIG, ECHO | Раннее обнаружение препятствия спереди — инициирует OBSTACLE_APPROACH
D10 (ШИМ) | Серво (рулевое) | Угол поворота
D9 (ШИМ) | L298N ENA | Скорость мотора
A4/A5 | MPU-6050 (I2C) | Гироскоп
D6,D11,D12,D13 | Датчик цвета | Определение RED/GREEN

Результат изменения

- Робот обнаруживает препятствие на ~35 см примерно за 0,97 секунды до контакта при скорости 0,36 м/с.
- За это время серво успевает плавно начать манёвр, а не делать резкий поворот.
- Датчик цвета по-прежнему определяет сторону объезда его роль не изменилась, изменился момент начала реакции.
- Ультразвук №1 (правый) по-прежнему контролирует расстояние до столба во время самого манёвра.

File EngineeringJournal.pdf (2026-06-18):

# Engineering Journal

# Ключевые факты:

Контроллер: Хаб LEGO Mindstorms EV3 + 2 мотора

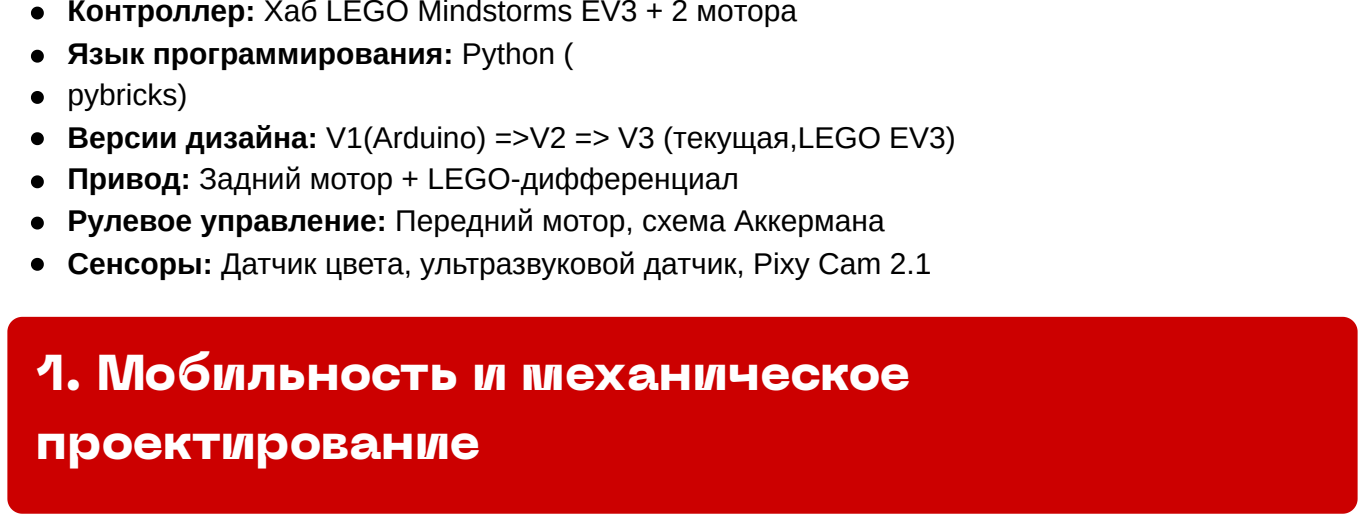
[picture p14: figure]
Язык программирования: Python ( pybricks); Привод: Задний мотор + LEGO-дифференциал; 1. Мобильность и механическое проектирование

Версии дизайна: V1(Arduino) =>V2 => V3 (текущая,LEGO EV3)

Рулевое управление: Передний мотор, схема Аккермана Сенсоры: Датчик цвета, ультразвуковой датчик, Pixy Cam 2.1

Задний мотор передаёт тягу через LEGO-дифференциал, обеспечивая равное распределение момента в повороте. Передний мотор отдельно управляет рулением по схеме Аккермана, где внутреннее и внешнее колесо поворачиваются на разный угол, что уменьшает проскальзывание. Используются колёса LEGO 86652c01.

Итерация | Описание | Решение / Рекомендация
V1 | Прототип на Arduino | Ненадёжный, не соответствовал регламенту
V2 | Первая сборка на EV3 | Ось переднего колеса слишком свободная, рама расшатывалась.Добавить камеру для выполнения заданий
V3 (Текущая) | Усиление крепления оси балками | Рекомендация на будущее: деталь LEGO Half-Bush #32124 внутри самого дифференциала для устранения причины люфта.

Пробуксовка колёс на повороте решена сменой покрытия колёс и снижением скорости на повороте.

V1:

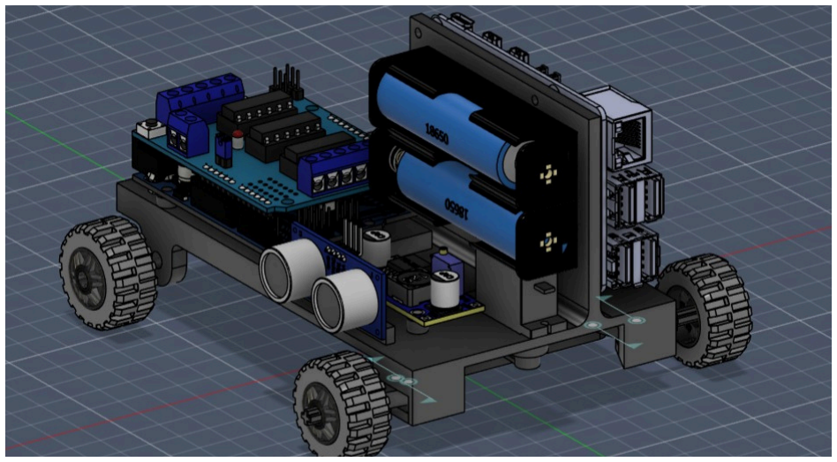
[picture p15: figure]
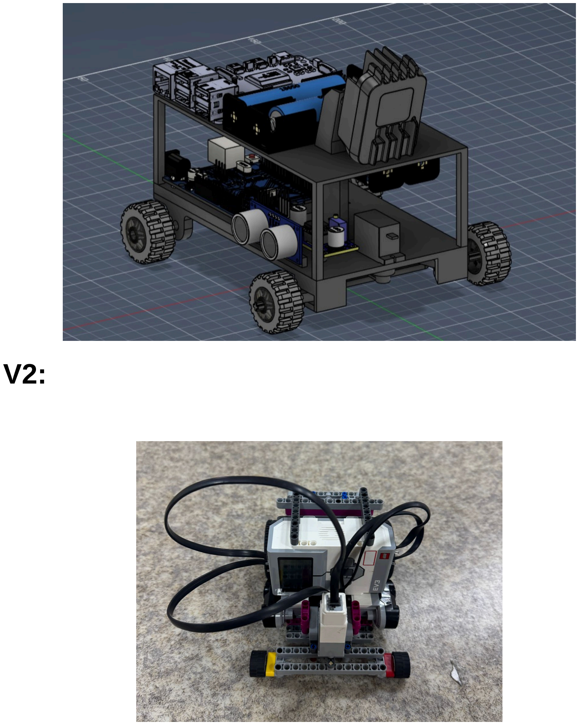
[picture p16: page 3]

V2:

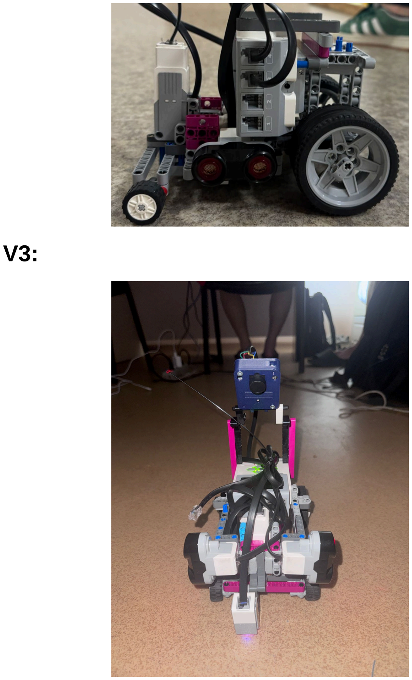
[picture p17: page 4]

V3:

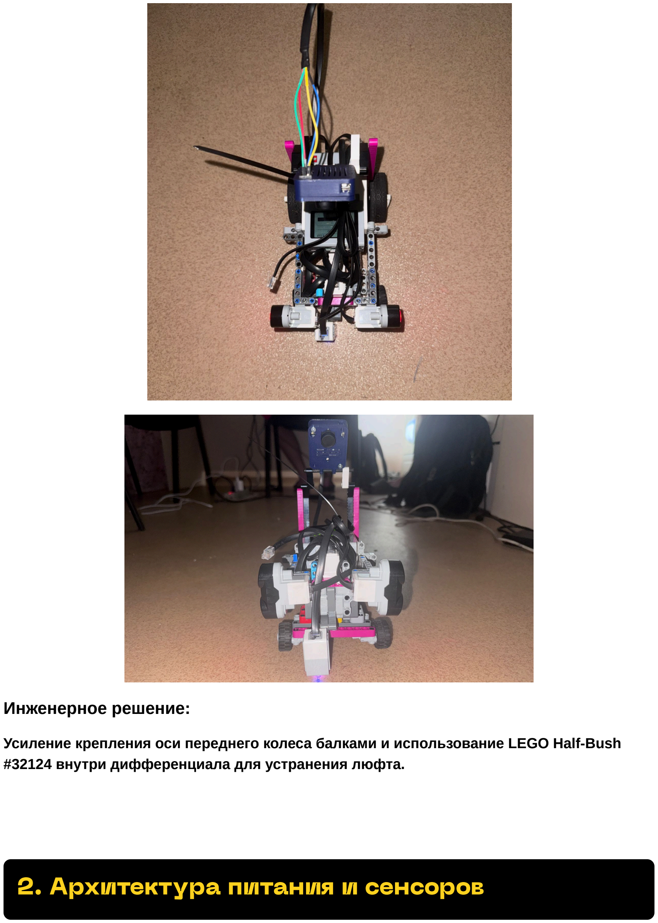
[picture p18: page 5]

Инженерное решение:

Усиление крепления оси переднего колеса балками и использование LEGO Half-Bush #32124 внутри дифференциала для устранения люфта.

## 2. Архитектура питания и сенсоров

Роли разделены между двумя системами восприятия:

Датчик цвета (спереди, направлен вниз) читает оранжевые/синие метки трассы и определяет сторону поворота.
Pixy Cam 2.1 (направлена на внешние объекты, не на трассу) определяет цвет препятствия и сторону объезда.

Замечено: Разряд батареи заметно снижает скорость робота. Мера: проверка заряда хаба перед заездом.

Калибровка:

Обучать цветовые сигнатуры Pixy Cam под освещение соревнования с разных углов. Устанавливать ультразвуковой датчик строго перпендикулярно стенам (отклонение не более 5°) и проверять на известных расстояниях (20/30/40 см).
Датчик цвета крепить жёстко на высоте 0,5–1 см над трассой.

Инженерное решение:

Разделение функций восприятия между датчиком цвета и Pixy Cam 2.1, с проверкой заряда батареи перед заездом.

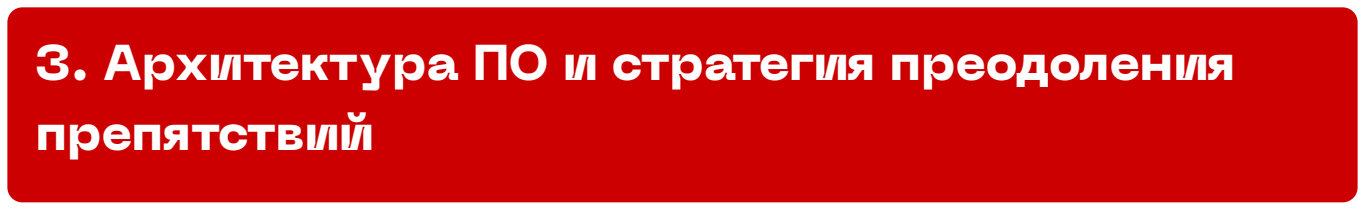
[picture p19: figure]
препятствий

## 3. Архитектура ПО и стратегия преодоления

Код написан на Python (pybricks). Текущая реализация: последовательный скрипт с if/else. Рекомендуется переход к реализации в виде конечного автомата:

1. Поиск метки
2. Следование по трассе
3. Поворот по метке (bang-bang логика на оранжевый/синий)
4. Обход препятствия (Pixy Cam)
5. Восстановление после потери линии

Открытые вопросы и риски:

Порог срабатывания ультразвука: пока не финализирован.
Потеря объекта камерой Pixy Cam: открытый риск. Рекомендуемое решение: подтверждать объект 2-3 кадрами подряд и делать повторные попытки чтения с таймаутом, а не реагировать на один кадр.

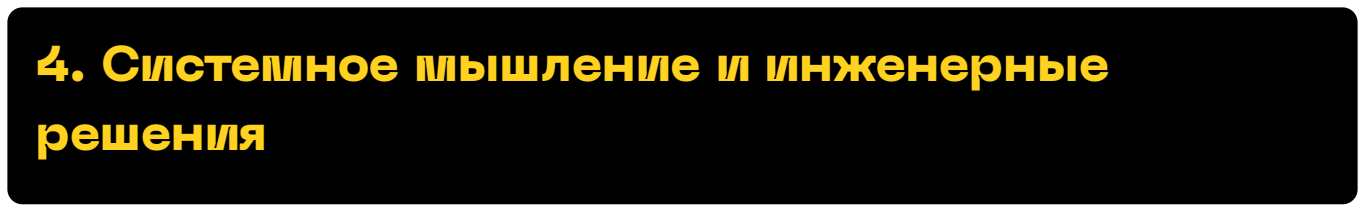
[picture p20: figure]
4. Системное мышление и инженерные решения

Карта подсистем включает: мобильность, питание, восприятие, вычисления, конструкция.

Таблица решений:

Критерий | Отклонено | Выбрано
Платформа | Arduino | LEGO EV3
Архитектура восприятия | Без камеры | Pixy Cam 2.1

Ограничения:

Всего 4 моторных и 4 сенсорных порта EV3. Ограниченное количество деталей LEGO и бюджет. Ограниченное время до соревнования.

Реестр рисков:

Разряд батареи
Расшатывание рамы
Пробуксовка колёс
Потеря объекта камерой

Инженерное решение:

Выбор LEGO EV3 как основной платформы и интеграция Pixy Cam 2.1 для расширенных возможностей восприятия, с учётом ограничений по портам и деталям.

Репозиторий содержит 5+ коммитов, но README требует расширения (цель 5000+ символов). Коммит-сообщения общие ('update', 'fix'). Схемы подключения отсутствуют.

Рекомендуемая структура репозитория:

Таблица BOM (Bill of Materials):

Позиция | Наименование | Количество | Примечание
1 | LEGO Mindstorms EV3 Hub | 1
2 | LEGO Motors (Large) | 2
3 | LEGO Technic Wheels | 4 | 86652c01
4 | LEGO Technic Differential | 1
5 | Pixy Cam 2.1 | 1
6 | LEGO Color Sensor | 1
7 | LEGO Ultrasonic Sensor | 1

Чек-лист доработок перед сдачей:

Расширить README.
Добавить схемы подключения.
Детализировать коммит-сообщения.
Финализировать порог срабатывания ультразвука. Реализовать механизм устойчивой детекции объектов Pixy Cam. Провести финальную калибровку всех сенсоров.
Заполнить таблицу BOM.

Инженерное решение:

Структурирование репозитория по папкам для улучшения воспроизводимости и добавление полного списка компонентов (BOM) с чек-листом доработок.

Задний мотор передаёт момент через дифференциал, который сам распределяет угловые скорости колёс по сопротивлению качению: внешнее колесо на повороте раскручивается быстрее внутреннего (ω_outer > ω_inner) без участия программы — синхронизация скоростей решается механически, а не программным контуром.

Геометрия Аккермана выражается через котангенсы углов поворота колёс: cot(θ_outer) − cot(θ_inner) = d / w, где d — колея, w — колёсная база. Рулевая рейка реализует это соотношение механически за счёт трапеции рычагов, поэтому программа управляет не углами левого и правого колеса по отдельности, а положением одного виртуального центрального колеса.

На старте, пока робот не привязан к стене, центрирование идёт сразу по двум дальномерам через нелинейную функцию f(x) = −2·√(11·x) + 100, где x — расстояние в см. Целевой угол рейки: target = 1.3·f(chap) − 1.3·f(rast), ограничен ±28°. Корневая зависимость работает как самонастраивающийся коэффициент усиления: чувствительность руля растёт вблизи стены и падает на расстоянии, что убирает паразитное рысканье на прямых участках без переключения режимов регулятора.

После определения стороны трассы включается классический П-регулятор удержания стены на дистанции 28 см: e(t) = (distance − 28)·Kp, где Kp = −2 для левой стены и +2 для правой. Так как рейка управляется через энкодер мотора, регулятор берёт рассогласование Δ = e(t) − position(motor) и ограничивает его clamp(Δ, −35, 35), защищая механику рейки от резких скачков сигнала.

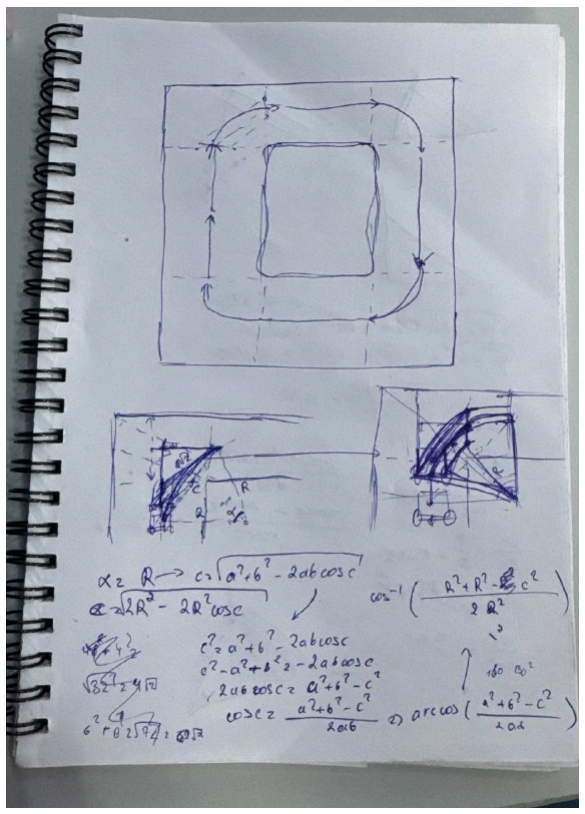
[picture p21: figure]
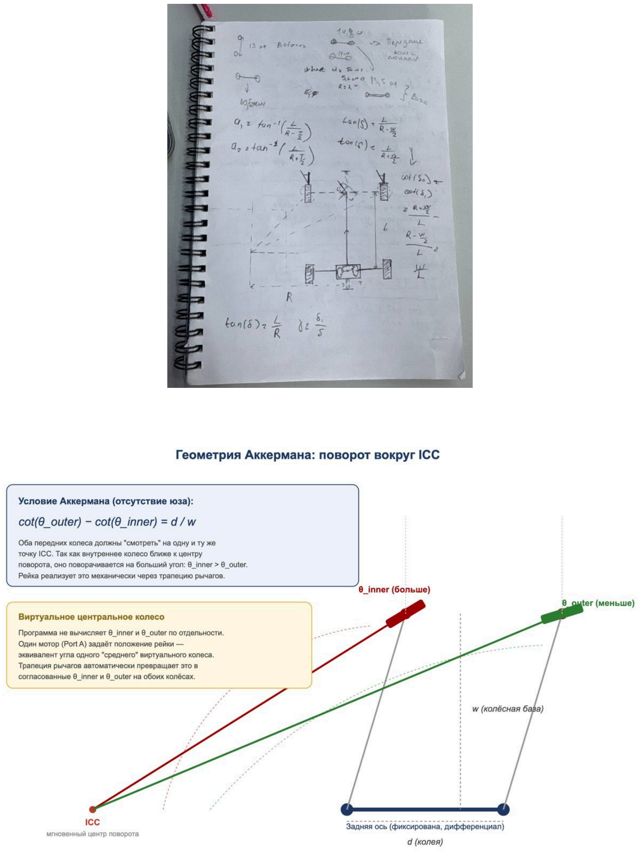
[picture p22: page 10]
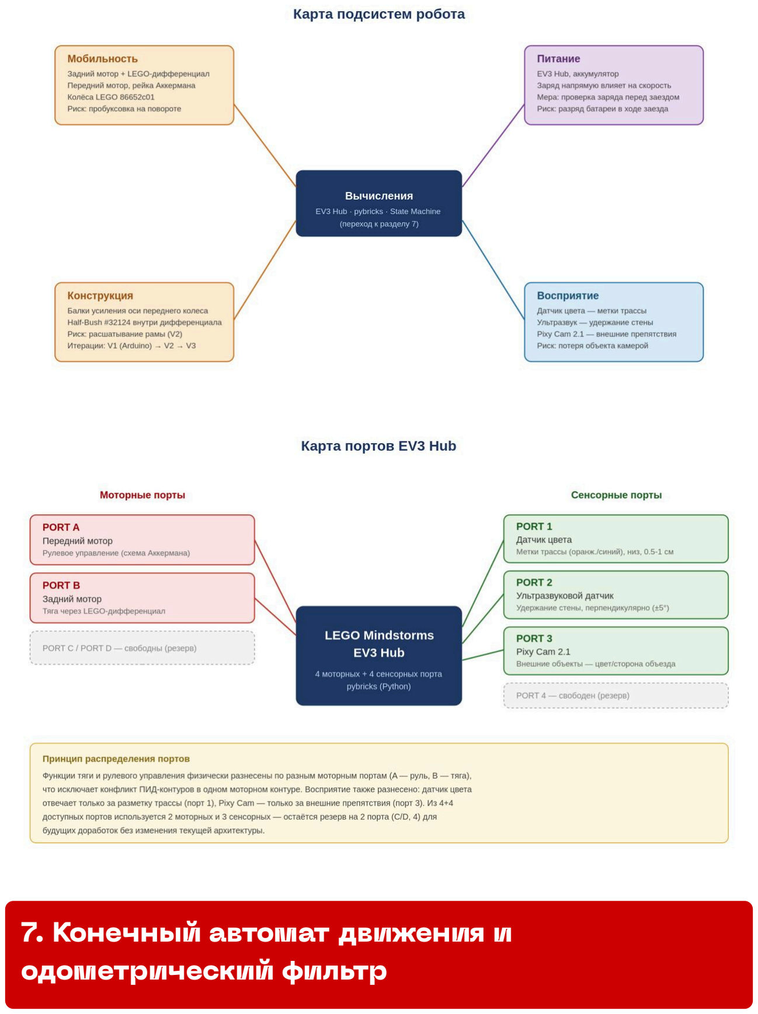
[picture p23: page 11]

## 7. Конечный автомат движения и одометрический фильтр

Алгоритм построен как трёхэтапный конечный автомат, где переходы определяются датчиками и одометрией, а не таймерами — это снижает зависимость от трения, заряда батареи и точности стартовой установки.

Stage 1=> старт и сканирование: центрирование по двум дальномерам, пока датчик цвета не зафиксирует первый маркер.

Stage 2 => движение с привязкой к одной стене: направление объезда (по/против часовой) не задаётся в коде заранее, а определяется первым цветным маркером (синий/чёрный → LEFT, оранжевый/красный → RIGHT) — это убирает ошибку человеческого фактора при настройке перед заездом.

Stage 3 => финишный створ: после засчитанной финальной линии датчик цвета отключается, и ещё около 60 итераций цикла удержания стены доводят робота до полной остановки внутри финишного коридора, не обрывая движение точно на пересечении последней линии.

Один и тот же маркер может быть прочитан датчиком цвета несколько раз подряд из-за дребезга на границе цвета. Защита от повторного счёта реализована не задержкой по времени, а по одометрии: энкодер маршевого мотора сбрасывается в нуль перед каждым засчитанным маркером, и новое срабатывание засчитывается только после поворота вала больше чем на 1000° расстояние, заведомо превышающее ширину маркера. Это делает фильтр нечувствительным к скорости движения робота.

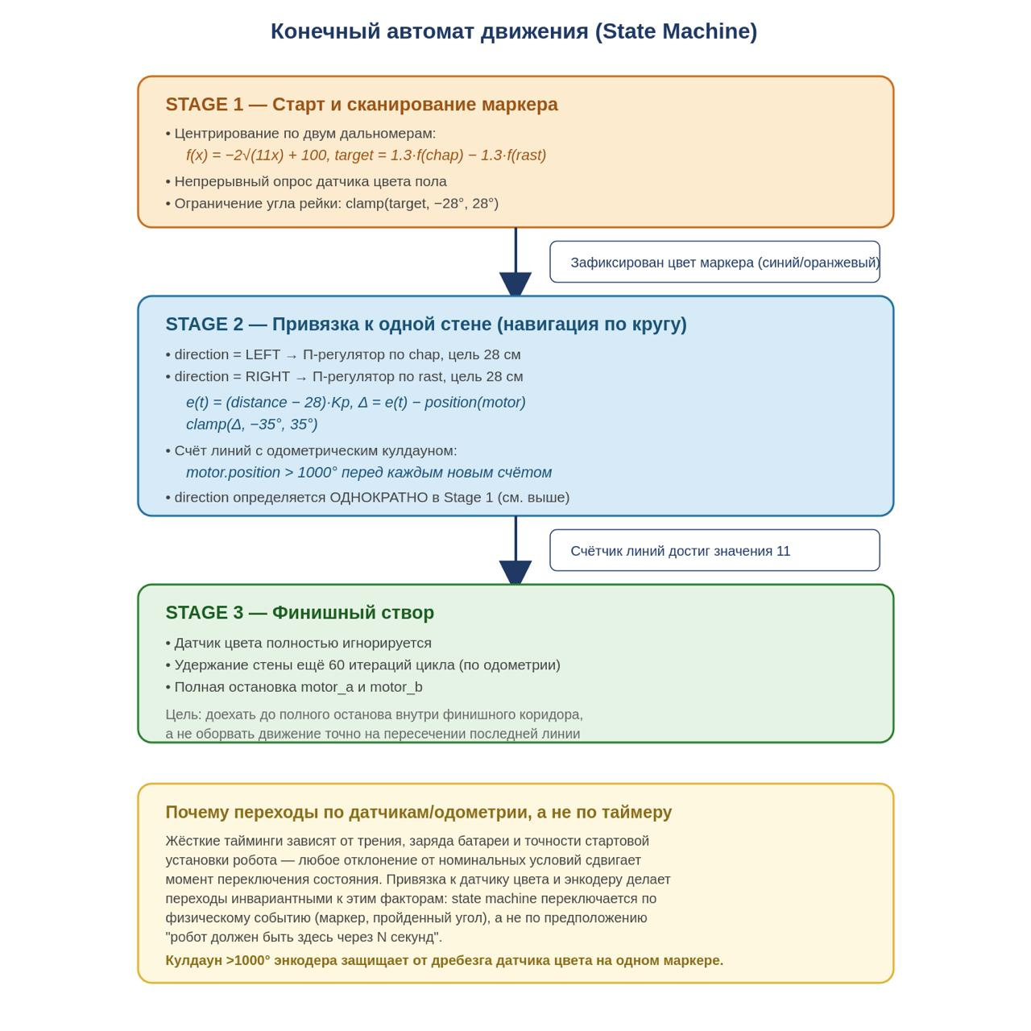
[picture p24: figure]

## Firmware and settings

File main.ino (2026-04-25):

#include <Wire.h>
#include <Servo.h>

// --- КОНФИГУРАЦИЯ ПИНОВ ---
const int PIN_ENA = 5;  const int PIN_IN1 = 6;  const int PIN_IN2 = 7;
const int PIN_SERVO = 9;
const int PIN_TRIG_F = 8; const int PIN_ECHO_F = 10; // Передний датчик
const int PIN_TRIG_S = 11; const int PIN_ECHO_S = 12; // Боковой (правый) датчик
const int MPU_ADDR = 0x68;

Servo steer;

// --- ПАРАМЕТРЫ ДВИЖЕНИЯ ---
int CENTER = 180;         // Твоя точка прямолинейного движения
int BASE_SPEED = 255;     // Скорость на прямых
int TARGET_DIST = 35;     // Дистанция до стены в см
bool isClockwise = false;  // Поменяй на false, если едешь против часовой

// PID коэффициенты для езды вдоль стены
float kp = 4.0; 
float kd = 1.5;
float lastSideError = 0;

// Переменные гироскопа
float currentAngle = 0;
unsigned long lastTime;

// Состояния робота
enum State { FOLLOW_WALL, TURN };
State currentState = FOLLOW_WALL;
float turnTargetAngle = 0;

void setup() {
  Serial.begin(9600);
  Wire.begin();
  steer.attach(PIN_SERVO);
  steer.write(CENTER);

  pinMode(PIN_ENA, OUTPUT); pinMode(PIN_IN1, OUTPUT); pinMode(PIN_IN2, OUTPUT);
  pinMode(PIN_TRIG_F, OUTPUT); pinMode(PIN_ECHO_F, INPUT);
  pinMode(PIN_TRIG_S, OUTPUT); pinMode(PIN_ECHO_S, INPUT);

  // Старт MPU6050
  Wire.beginTransmission(MPU_ADDR);
  Wire.write(0x6B); Wire.write(0);
  Wire.endTransmission(true);

  delay(3000); // Время поставить робота на старт
  lastTime = millis();
}

void loop() {
  updateAngle();
  int distFront = getDist(PIN_TRIG_F, PIN_ECHO_F);
  int distSide = getDist(PIN_TRIG_S, PIN_ECHO_S);

  if (currentState == FOLLOW_WALL) {
    // Езда прямо вдоль стены
    driveStraight(distSide);
    
    // Если стена впереди близко — начинаем поворот
    if (distFront > 5 && distFront < 60) {
      currentState = TURN;
      if (isClockwise) turnTargetAngle = currentAngle - 85; // Поворот направо
      else turnTargetAngle = currentAngle + 85;            // Поворот налево
    }
  } 
  else if (currentState == TURN) {
    // Режим поворота
    executeTurn();
  }
}

// Функция езды вдоль стены (PID)
void driveStraight(int currentDist) {
  float error = currentDist - TARGET_DIST;
  float p = error * kp;
  float d = (error - lastSideError) * kd;
  lastSideError = error;

  float correction = p + d;
  
  // Если едем против часовой, инвертируем руль
  if (!isClockwise) correction = -correction;

  int angle = CENTER + constrain(correction, -30, 30);
  steer.write(angle);
  
  moveMotors(BASE_SPEED);
}

// Функция поворота по гироскопу
void executeTurn() {
  int turnSteer;
  if (isClockwise) {
    turnSteer = CENTER - 30; // Выворачиваем руль вправо (учти, CENTER у тебя 210)
    if (currentAngle <= turnTargetAngle) currentState = FOLLOW_WALL;
  } else {
    turnSteer = CENTER + 30; // Выворачиваем руль влево
    if (currentAngle >= turnTargetAngle) currentState = FOLLOW_WALL;
  }
  
  steer.write(turnSteer);
  moveMotors(BASE_SPEED - 20); // Чуть медленнее на повороте
}

// Вспомогательные функции
void moveMotors(int speed) {
  digitalWrite(PIN_IN1, HIGH);
  digitalWrite(PIN_IN2, LOW);
  analogWrite(PIN_ENA, speed);
}

int getDist(int trig, int echo) {
  digitalWrite(trig, LOW); delayMicroseconds(2);
  digitalWrite(trig, HIGH); delayMicroseconds(10);
  digitalWrite(trig, LOW);
  long duration = pulseIn(echo, HIGH, 30000); // Таймаут 30мс
  int dist = duration * 0.034 / 2;
  if (dist == 0) return 400; // Если ничего не видит
  return dist;
}

void updateAngle() {
  unsigned long now = millis();
  float dt = (now - lastTime) / 1000.0;
  lastTime = now;

  Wire.beginTransmission(MPU_ADDR);
  Wire.write(0x47);
  Wire.endTransmission(false);
  Wire.requestFrom(MPU_ADDR, 2, true);
  int16_t gz = Wire.read()<<8|Wire.read();
  
  float gyroRate = gz / 131.0;
  if (abs(gyroRate) > 0.3) currentAngle += gyroRate * dt;
}

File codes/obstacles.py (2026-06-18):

#!/usr/bin/env pybricks-micropython
from pybricks.hubs import EV3Brick
from pybricks.ev3devices import Motor, UltrasonicSensor, ColorSensor
from pybricks.parameters import Port, Color, Button
from pybricks.iodevices import I2CDevice
from pybricks.tools import wait, StopWatch
import math

# --- ИНИЦИАЛИЗАЦИЯ ---
ev3 = EV3Brick()
ev3.light.on(Color.ORANGE)

chap = UltrasonicSensor(Port.S1)    # Левый УЗ
rast = UltrasonicSensor(Port.S2)    # Правый УЗ
color_sensor = ColorSensor(Port.S3) # Датчик цвета в пол

motor_b = Motor(Port.A) # Ходовой мотор
motor_a = Motor(Port.B) # Рулевой мотор (Аккерман)

try:
    pixy = I2CDevice(Port.S4, 0x54)
    print("Pixy2.1: OK")
except:
    print("Pixy2.1: ERROR!")

motor_a.reset_angle(0)
motor_b.reset_angle(0)

print("Ждем старт...")
while Button.CENTER not in ev3.buttons.pressed():
    wait(10)

ev3.light.on(Color.GREEN)
ev3.speaker.beep(frequency=400, duration=200)
wait(200)
print("СТАРТ")

# --- НАСТРОЙКИ ---
speed = 800 # Скорость

abi = [Color.BLUE, Color.BLACK]
narengi = [Color.ORANGE, Color.RED]

direction = None
line_counter = 0

# Фильтры УЗ истории
left_history = [30.0, 30.0, 30.0]
right_history = [30.0, 30.0, 30.0]
filtered_target = 0.0

blue_count = 0
orange_count = 0

# --- СЛУЖЕБНЫЕ ФУНКЦИИ ---
def clamp(value, mn, mx):
    if value > mx: return mx
    if value < mn: return mn
    return value

def median3(arr):
    s = sorted(arr)
    return s[1]

def get_left():
    global left_history
    d = chap.distance() / 10.0
    if 5.0 < d < 150.0:
        left_history.append(d)
        left_history.pop(0)
    return median3(left_history)

def get_right():
    global right_history
    d = rast.distance() / 10.0
    if 5.0 < d < 150.0:
        right_history.append(d)
        right_history.pop(0)
    return median3(right_history)

def amotor(target_angle, max_speed=800):
    clamped_angle = clamp(target_angle, -35, 35) # Максимальный выворот ограничен 35 градусами
    motor_a.run_target(max_speed, clamped_angle, wait=False)

def smooth(value):
    global filtered_target
    filtered_target = filtered_target * 0.7 + value * 0.3
    return filtered_target

def parse_pixy_blocks():
    request = bytes([174, 193, 32, 2, 3, 5])
    try:
        pixy.write(0, request)
        reply = pixy.read(0, 20)
        if reply[0] == 175 and reply[1] == 193:
            sig = reply[7] << 8 | reply[6]
            x_val = reply[9] << 8 | reply[8]
            y_val = reply[11] << 8 | reply[10]
            width = reply[12]
            if width > 10 and sig <= 7:
                return sig, x_val, y_val
    except:
        pass
    return 0, 157, 0

# ==================================================
# ЭТАП 1: ПОИСК ПЕРВОЙ ЛИНИИ (ОПРЕДЕЛЕНИЕ НАПРАВЛЕНИЯ)
# ==================================================
print("Поиск первой линии...")

while direction is None:
    motor_b.run(speed)
    r = get_right()
    c = get_left()

    fr = (-2 * math.sqrt(11 * r)) + 100
    fc = (-2 * math.sqrt(11 * c)) + 100
    target = (fc * 1.3) - (fr * 1.3)
    
    amotor(smooth(target))

    color = color_sensor.color()
    if color in abi: blue_count += 1
    else: blue_count = 0

    if color in narengi: orange_count += 1
    else: orange_count = 0

    if blue_count >= 3:
        direction = "LEFT"
        line_counter = 1
        motor_b.reset_angle(0)
        print("Направление LEFT")
        break

    if orange_count >= 3:
        direction = "RIGHT"
        line_counter = 1
        motor_b.reset_angle(0)
        print("Направление RIGHT")
        break

    wait(5)

# ==================================================
# ЭТАП 2: ОСНОВНОЙ ЗАЕЗД (С ПРЕПЯТСТВИЯМИ)
# ==================================================
print("Основной цикл")

while True:
    motor_b.run(speed)

    # 1. СЧЕТЧИК ЛИНИЙ
    color = color_sensor.color()
    if color in abi: blue_count += 1
    else: blue_count = 0

    if color in narengi: orange_count += 1
    else: orange_count = 0

    line_detected = (blue_count >= 3 or orange_count >= 3)

    if motor_b.angle() > 1000 and line_detected:
        line_counter += 1
        motor_b.reset_angle(0)
        print("Линия:", line_counter)
        blue_count = 0
        orange_count = 0

    # Если нужно проехать ровно 1 круг (в зависимости от разметки, обычно это 4, 8 или 12 линий)
    # Поменяй число 12 на то, которое у тебя означает финиш.
    if line_counter == 12: 
        break

    # 2. ОПРОС КАМЕРЫ PIXY
    sig, x_val, y_val = parse_pixy_blocks()
    if y_val < 35: 
        sig = 0 # Игнорируем столбы, которые слишком далеко (на горизонте)

    # 3. ЛОГИКА РУЛЕНИЯ (УЛЬТРАЗВУК + КАМЕРА)
    if sig == 1:
        # ВИДИМ КРАСНЫЙ СТОЛБ: Объезжаем справа (столб должен быть слева в кадре)
        error = x_val - 45 # Идеальный X для красного = 45
        target = error * 1.5 # Жесткий коэффициент для максимального выворота
        amotor(smooth(target))

    elif sig == 2:
        # ВИДИМ ЗЕЛЕНЫЙ СТОЛБ: Объезжаем слева (столб должен быть справа в кадре)
        error = x_val - 270 # Идеальный X для зеленого = 270
        target = error * 1.5 
        amotor(smooth(target))

    else:
        # СТОЛБОВ НЕТ: Едем по стенам (Это предотвратит инверсию на поворотах и вернет руль в ноль!)
        if direction == "LEFT":
            distance = get_left()
            target = (distance - 28) * -2
            amotor(smooth(target))
        elif direction == "RIGHT":
            distance = get_right()
            target = (distance - 28) * 2
            amotor(smooth(target))

    wait(5)

# ==================================================
# ЭТАП 3: ДОЕЗД ДО ФИНИША И ОСТАНОВКА
# ==================================================
print("Финальный участок")
timer = StopWatch()
timer.reset()

while timer.time() < 600:
    motor_b.run(speed)
    if direction == "LEFT":
        distance = get_left()
        target = (distance - 28) * -2
        amotor(smooth(target))
    else:
        distance = get_right()
        target = (distance - 28) * 2
        amotor(smooth(target))
    wait(5)

# ФИНИШ
motor_b.stop()
motor_a.run_target(600, 0) # Ровняем колеса
ev3.light.on(Color.RED)
print("Заезд завершен")

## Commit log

2026-04-25 Add Scuderia Ferrari project files
    [2nd floor.stl, Arduino raiser.stl, Camera Holder Top.stl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]
2026-06-15 Expand README: speed torque calculation, port calibration, power budget, benchmarking, and instructions
2026-06-18 Add obstacles avoidance logic
    [obstacles.py]
2026-06-18 Complete repository overhaul: restructured folders, enhanced README, added BOM and documentation based on Engineering Journal
    [2nd floor.stl, Arduino raiser.stl, Camera Holder Top.stl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]
